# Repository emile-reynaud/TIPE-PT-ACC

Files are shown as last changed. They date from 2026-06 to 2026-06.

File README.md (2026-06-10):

# Régulateur de vitesse adaptatif et boucle de rétroaction PID
## TIPE PTSI-PT
### 2024-2026

---

## Sommaire

0. [Description générale](#desc)
   - [Problématique](#prob)
   - [Ancrage au thème *Cycles et boucles*](#anc-th)
1. [Maquette](#model)
2. [Architecture du correcteur](#arch-corr)
   - [Description de feedforward](#desc-ff)
   - [Identification du moteur](#id-mot)
3. [Mesure de vitesses](#mes-vit)
4. [Protocole expérimental](#prot-exp)
5. [Résultats](#results)
   - [Correcteur P](#P-results)
   - [Correcteur PI](#PI-results)
   - [Correcteur PD](#PD-results)
   - [Correcteur PID](#PID-results)
6. [Conclusion](#concl)
7. [Annexes et bibliographies](#annex)

---

## <a name="desc">Description générale</a>

Ce repo est un projet de recherche motivé par l'épreuve de TIPE du concours Banque PT.

Le projet est de construire une maquette d'un **régulateur de vitesse adaptatif** ou **ACC** (**A**daptive **C**ruise **C**ontrol), et de faire des expériences sur sa boucle de correction pour comparer les différents correcteurs **P**roportionnel (**P**), **P**roportionnel-**I**ntégral (**PI**), **P**roportionnel-**D**érivé (**PD**) et **P**roportionnel-**I**ntégral-**D**érivé (**PID**).

### <a name="prob">Problématique</a>

Comment un régulateur de vitesse adaptatif fonctionne-t-il, et comment sa boucle de correction PID se comporte-t-elle ?

### <a name="anc-th">Ancrage au thème *Cycles et boucles*</a>

Ce TIPE se concentre sur la **boucle** de rétroaction, ou **boucle** de correction, du système. Le **cycle** de correction est éffectué toutes les 50 ms.

## <a name="model">Maquette</a>

La maquette est composée d'une voiture RC modifiée et équipée de :

- Moteur brushed RC390
- Pont en H L298N
- Arduino Nano Every
- Arduino Nano Connector Carrier
- Capteur de distance à ultrasons HC-SR04
- Capteur à effet Hall + 3 aimants dans la roue arrière gauche
- Carte microSD branchée dans le Connector Carrier

##### Voici quelques images de la maquette

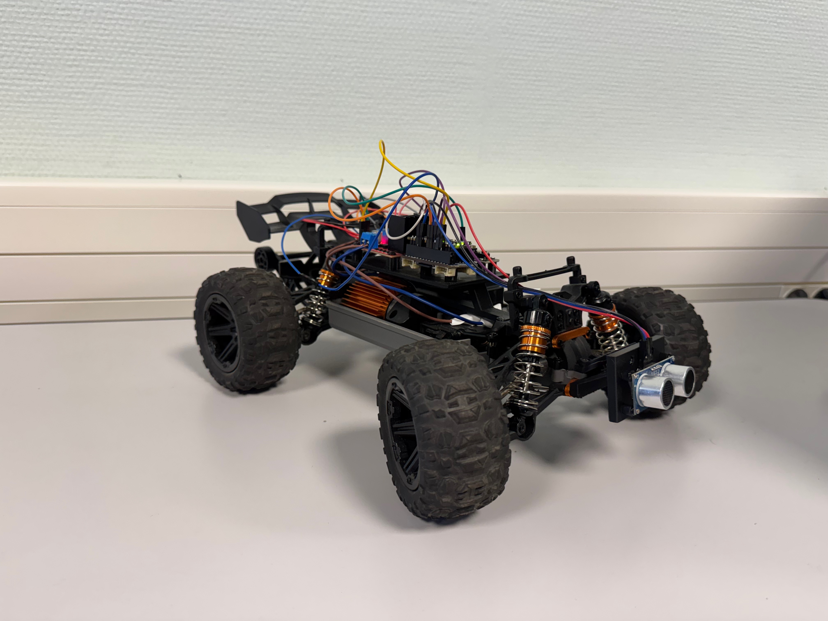
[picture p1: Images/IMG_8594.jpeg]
Model Overview 3/4 front right


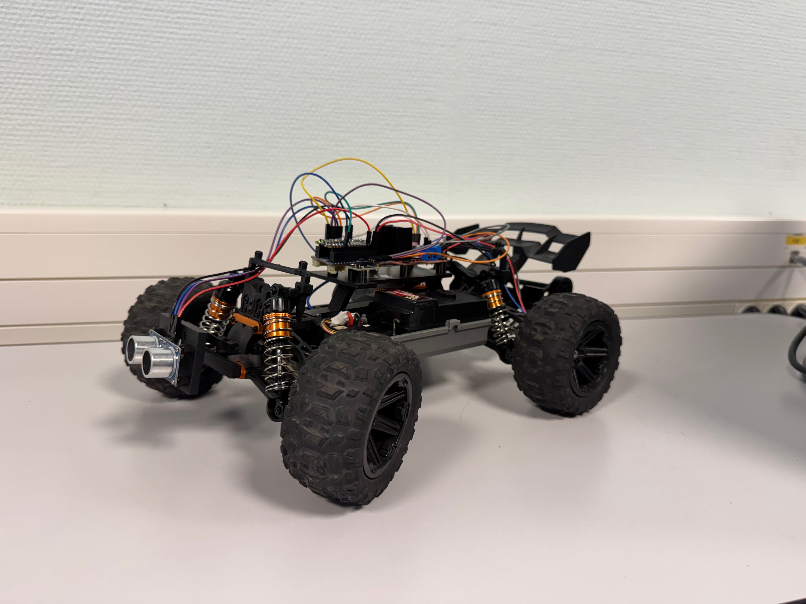
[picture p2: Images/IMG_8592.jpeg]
Model Overview 3/4 front left


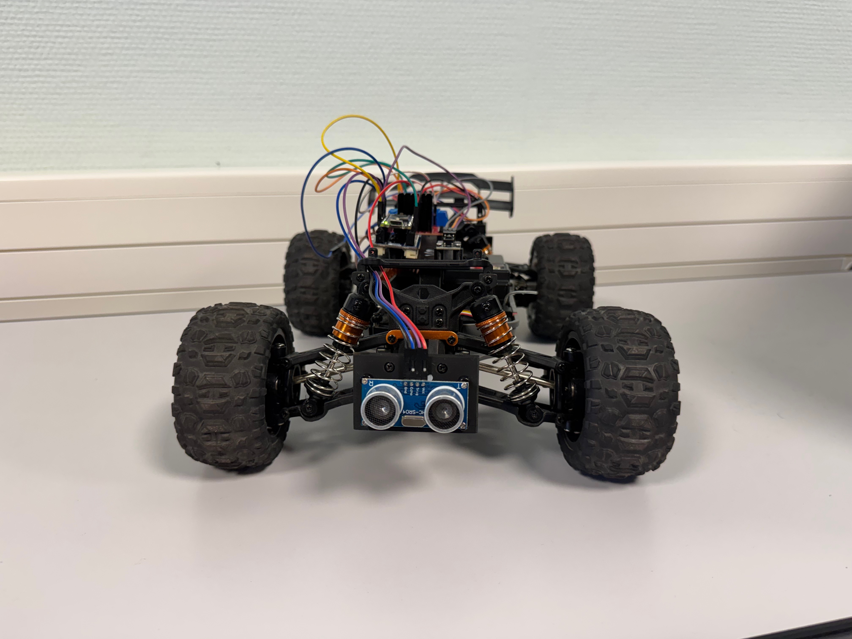
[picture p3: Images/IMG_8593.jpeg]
Model Overview face front


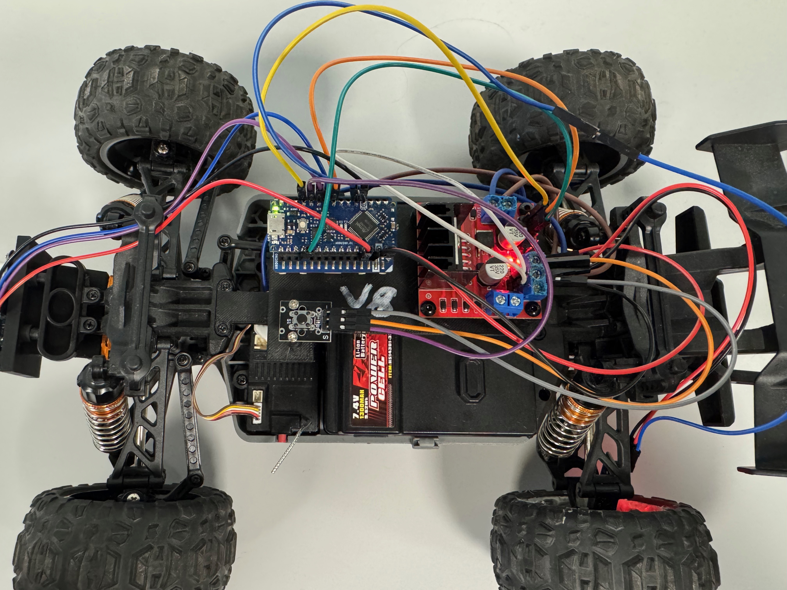
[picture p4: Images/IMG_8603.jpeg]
Electronics Overview


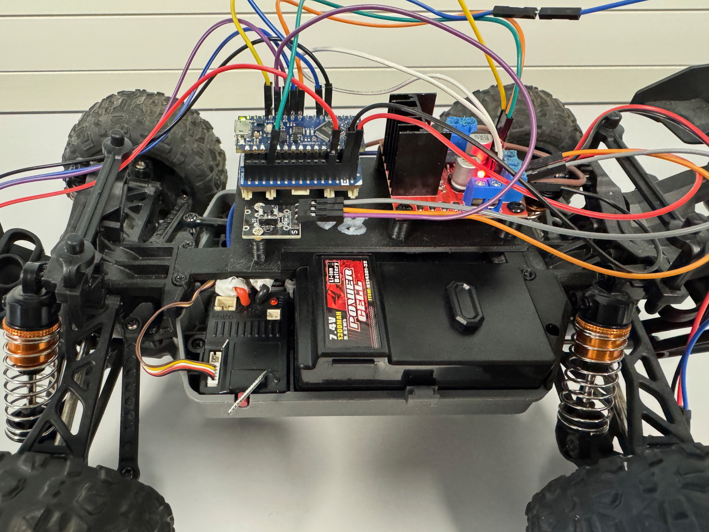
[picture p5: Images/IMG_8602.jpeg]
Electronics Overview left-side view


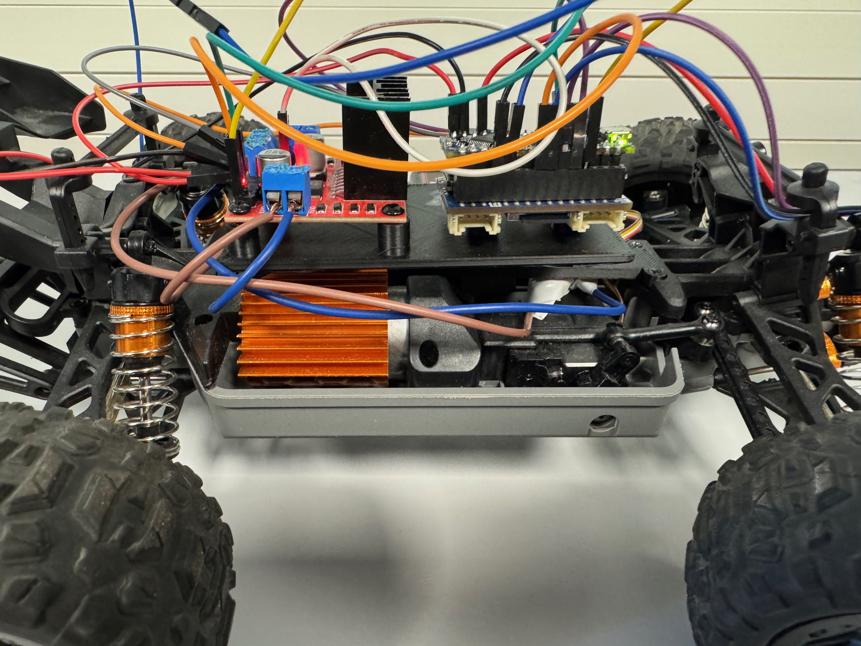
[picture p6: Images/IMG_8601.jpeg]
Electronics Overview right-side view


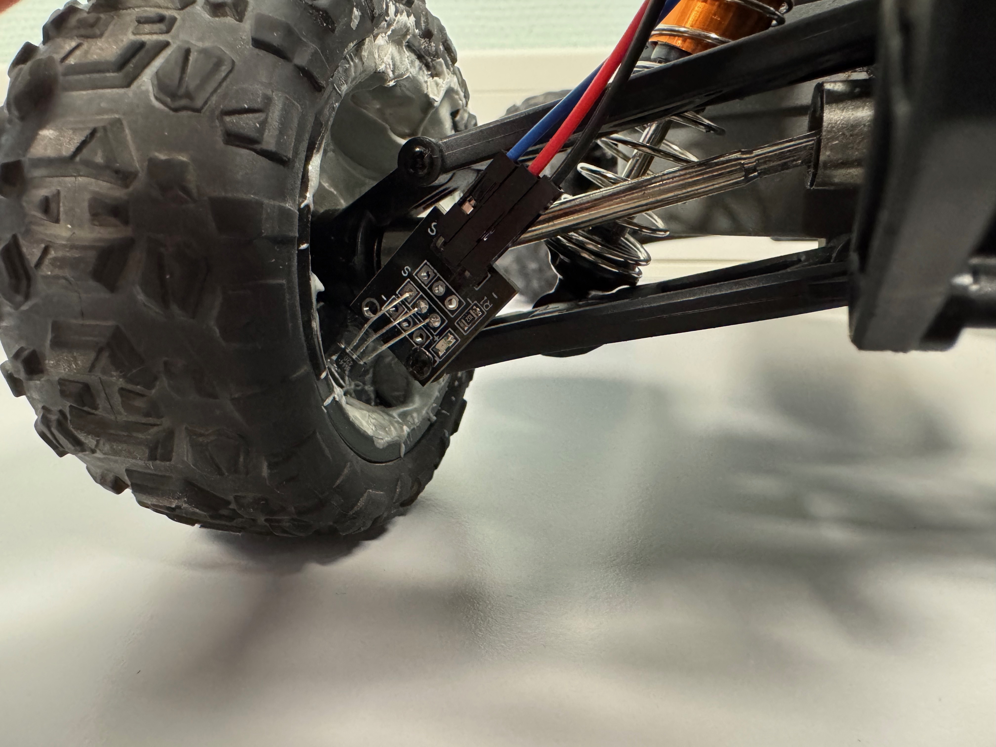
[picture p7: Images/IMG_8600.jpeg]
Hall effect sensor


## <a name="arch-corr">Architecture du correcteur</a>

Le correcteur se compose du régulateur PID, mais aussi d'un sytème de *feedforward*.

### <a name="desc-ff">Description du feedforward</a>

Le correcteur, qu'il soit P, PI, PD ou PID, prend une erreur en entrée et renvoie une commande moteur, et il veut faire tendre l'entrée vers 0.
Or, s'il fait cela, la commande qu'il retournera sera elle aussi 0.
Cependant, à 0, le moteur ne maintient pas sa vitesse à cause de la zone morte créée par le moteur en dessous de 76 PWM.

Voilà pour nous avons besoin dans ce sytème d'un **feedforward**.
Le feedforward est simplement un ajout après les correcteur, permettant de corriger cela et faire tendre la commande vers une commande en régime, et non en roue libre.
C'est une sorte d'offset de la commande.

### <a name="id-mot">Identification du moteur</a>

Pour calculer la valeur du feedforward, nous avons besoin d'identifier le moteur et de trouverson gain statique K, sa constante de temps $\tau$, ainsi que son seuil de commande.

Voici la fonction transfert d'un moteur à courant continu :

$\frac{dv}{dt} + \frac{1}{\tau}\cdot{v(t)} = K\cdot{u(t)}$

On trouve en la résolvant :

$v(t) = K\cdot{U_{0}}\cdot{(1-\exp(\frac{-t}{\tau}))}$
en réponse à un échelon U<sub>0</sub>

#### Protocole

- 9 échelons de 40 à 240 PWM, 3 s chacun.
- Mesure de v<sub>∞</sub> et $\tau$

#### Formules

On sait que :

$K = \frac{v_{\infty}}{U_{0}} \text{ et } v(\tau) = 0,632 \times v_{\infty}$

#### Résultats

- K = 1,4 m⋅s<sup>-1</sup>
- $\tau$ = 250 ms
- Seuil = 0,30 (= 76/255)

$\text{Donc } U_{FF} = (\frac{V_{c}}{K} + \{ Seuil }) = (\frac{0,7}{1,4} + 0,3) \times 255 = 204 \text{ PWM}$

Au final, la commande aura donc cette forme : 

$u(t) = U_{FF} + Kp \cdot \varepsilon + Ki \cdot \int \varepsilon \cdot dt + Kd \cdot \frac{d\varepsilon}{dt}$

## <a name="mes-vit">Mesure de vitesses</a>

La méthode de mesure de vitesse utilisée dans le programme est la **méthode période**. La méthode la plus commune est la méthode fréquencemétrique.

### Méthode fréquencemétrique

Le principe est de prendre un intervalle de temps et de compter le nombre de passage d'un objet, d'aimants dans mon cas, devant un capteur.
Je n'ai que 3 aimants donc les incertitudes dépendent de la vitesse et sont donc très grandes à basse vitesse notamment.

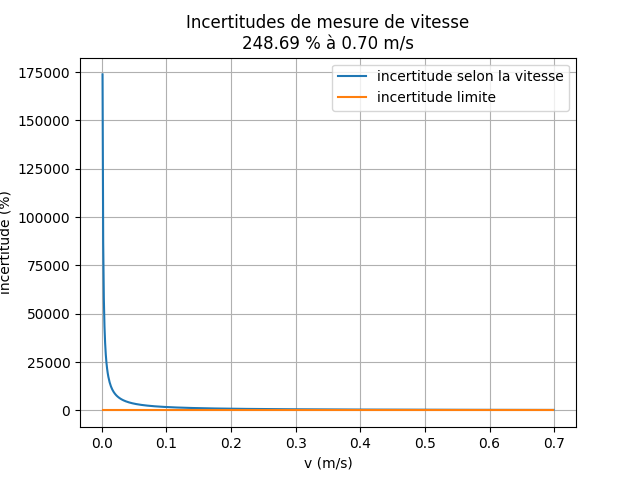
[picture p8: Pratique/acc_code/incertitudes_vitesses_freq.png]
Courbes incertitudes méthode fréquencemétrique


### Méthode période

C'est l'inverse de la méthode fréquencemétrique. On mesure le temps entre le passage de deux aimants.
L'incertitude est donc moins grande et surtout elle est constante.

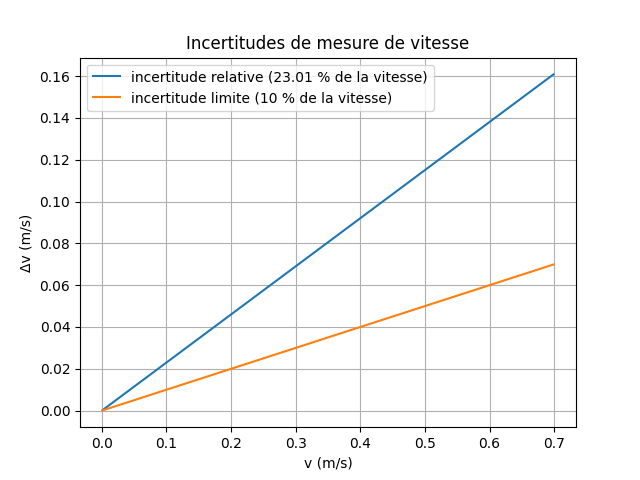
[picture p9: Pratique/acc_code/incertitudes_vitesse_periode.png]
Courbes incertitudes méthode période


## <a name="prot-exp">Protocole expérimental</a>

- Démarrage : 0-3s
  - Kick-start moteur pour franchir la zone morte et les frottements
- Mode vitesse : 3-12s
  - Aucun obstacle
- Mode distance : 12-27s
  - 12-15s : obstacle 0,6 m → 0,15 m
  - 15-21s : obstacle maintenu à 0,15 m
  - 21-27s : obstacle 0,15 m → 1,20 m
- Mode vitesse : 27-35s

## <a name="results">Résultats</a>

### <a name="P-results">Correcteur P</a>

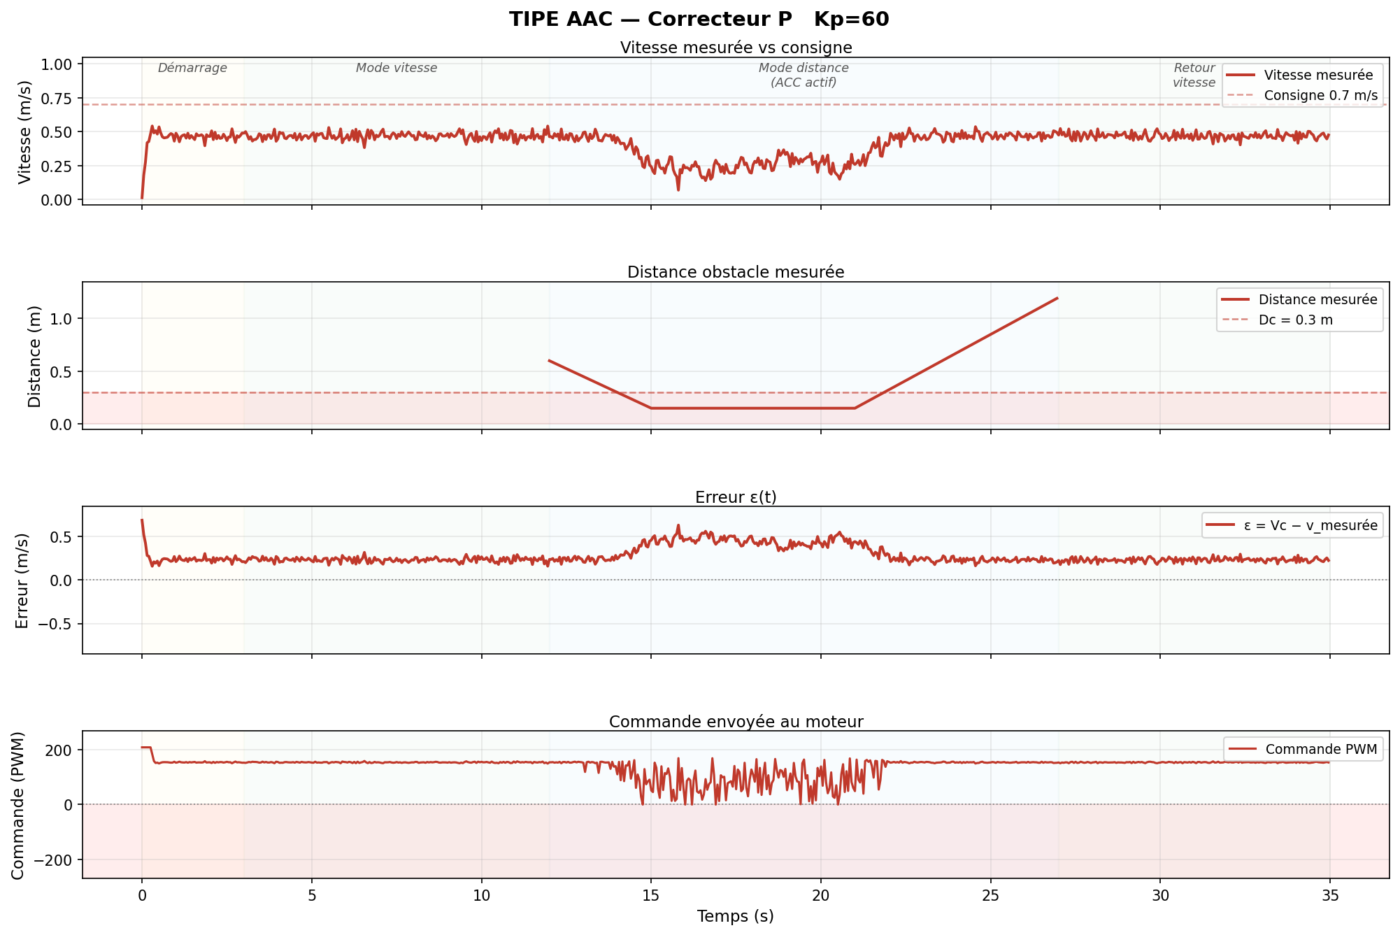
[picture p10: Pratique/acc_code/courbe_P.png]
Courbes expérimentales P


#### Analyse

##### Positif

- Kick-start efficace
- Commande stable à 170-180 PWM en régime sans obstacle

##### Limites

- Erreur statique -0,23 m⋅s<sup>-1</sup> (33%) structurelle sans intégrale
- Commande saccadée en mode distance (bruit amplifié par Kp)
- t<sub>r<sub>5%</sub></sub> = N/A, la vitesse ne converge jamais vers V<sub>c</sub>

#### Bilan

L'erreur statique de 33 % est irréductible sans terme intégral. Sert de référence comparative.

### <a name="PI-results">Correcteur PI</a>

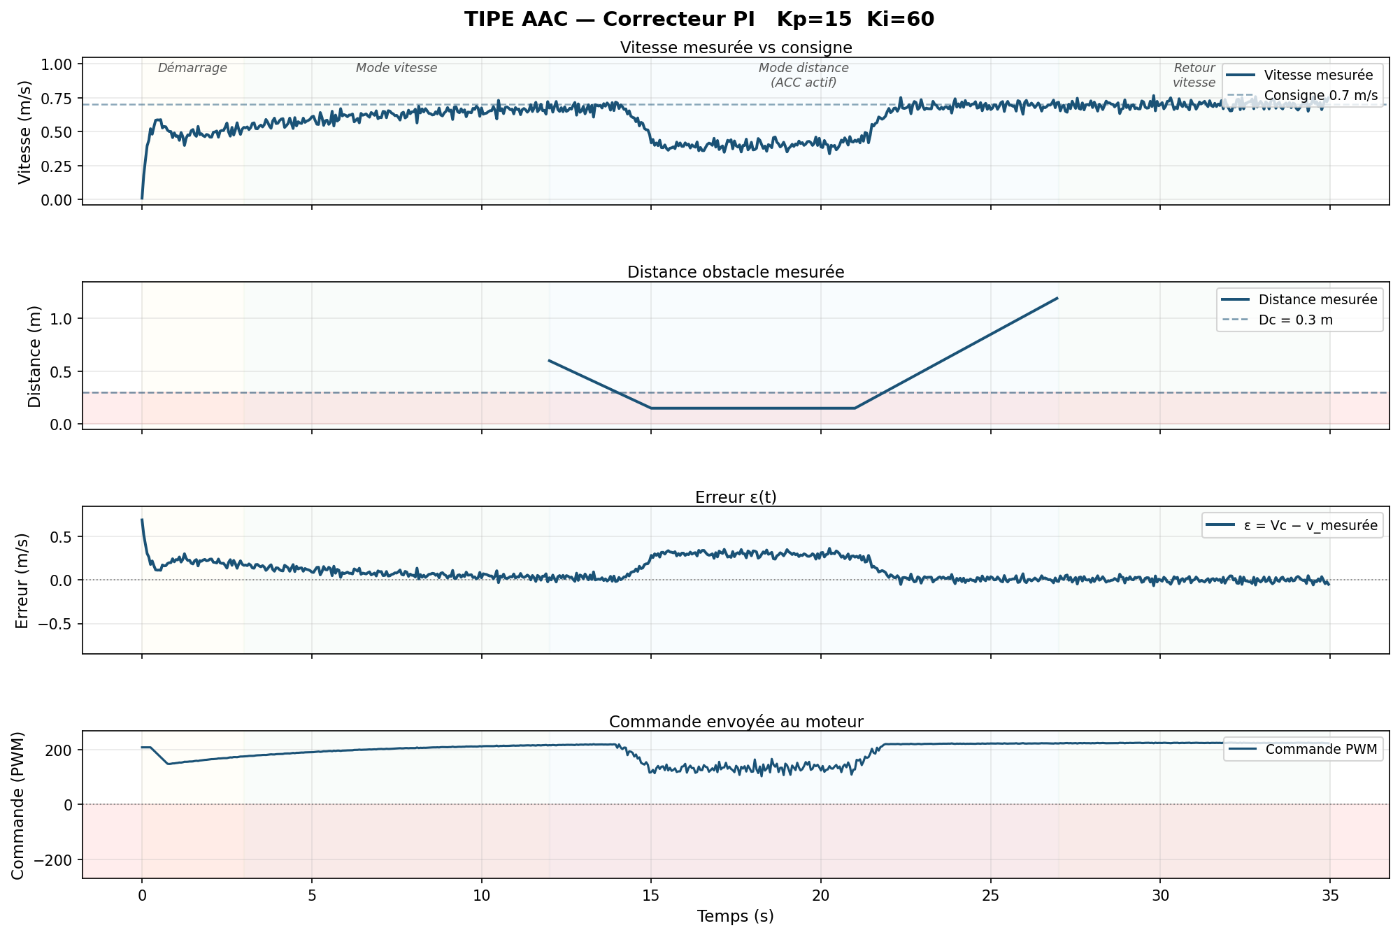
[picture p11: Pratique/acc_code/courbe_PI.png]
Courbes expérimentales PI


#### Analyse

##### Positif

- Erreur statique → 0 : Ki compense l'erreur
- Aucun dépassement, système très amorti
- Transition entre les modes propres, pas de saut

##### Limites

- t<sub>r<sub>5%</sub></sub> = 7,5 s, le plus lent des correcteurs
- Kp = 15 volontairement faible, peu réactif au perturbations soudaines
- Réinitialisation de l'intégrale au kick, convergence repart à zéro après démarrage

#### Bilan

Le PI atteint la précision au prix de la rapidité. t<sub>r<sub>5%</sub></sub> = 7,5 s est rédhibitoire en conditions réelles. À 0,70 m⋅s<sup>-1</sup>, la voiture parcourt 5 mètres avant d'être à vitesse.

### <a name="PD-results">Correcteur PD</a>

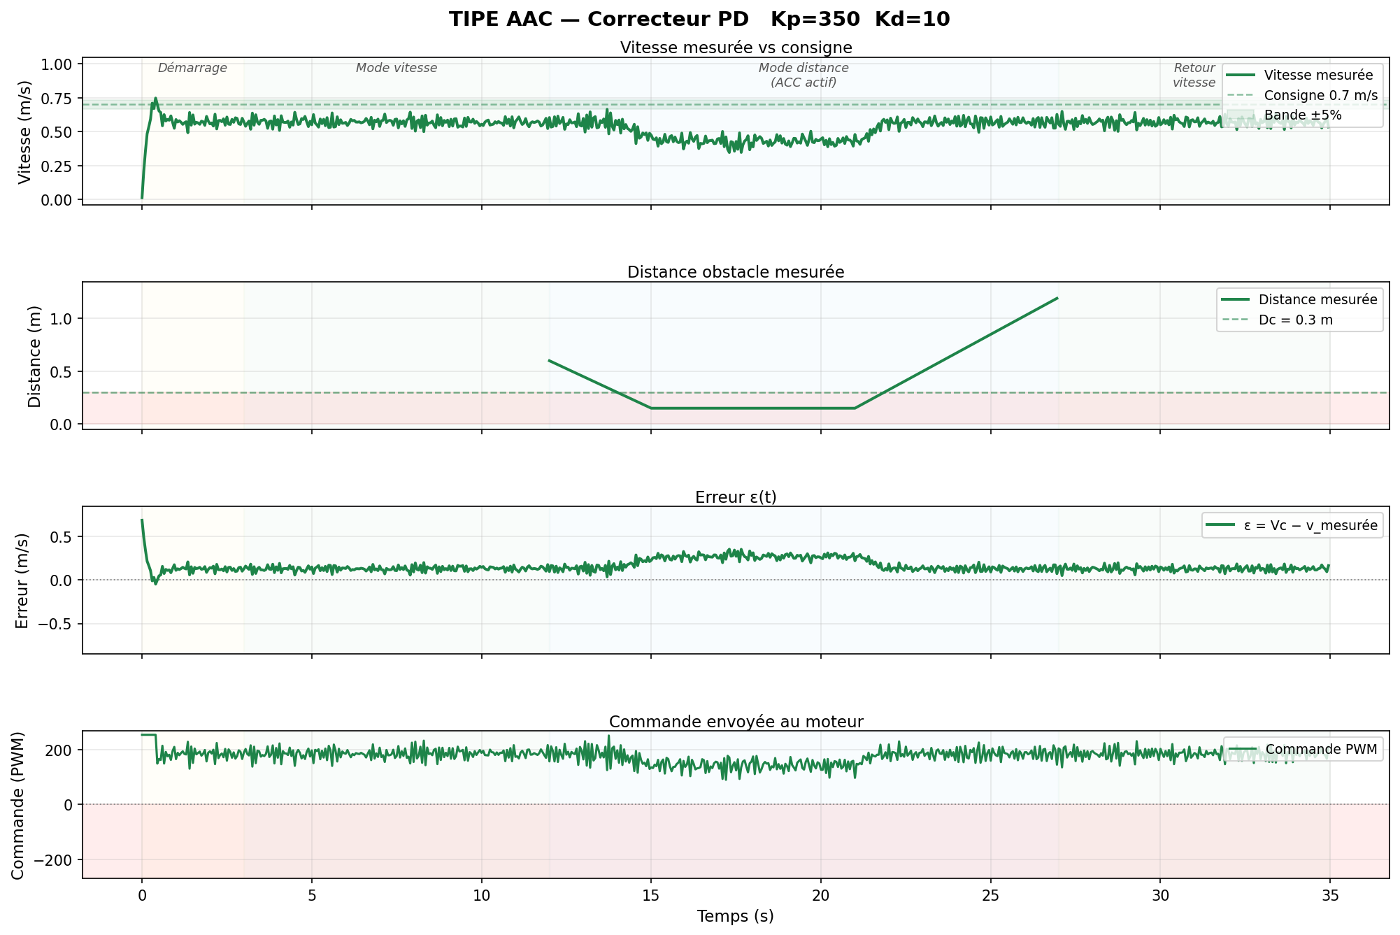
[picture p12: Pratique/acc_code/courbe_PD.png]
Courbes expérimentales PD


#### Analyse

##### Positif

- t<sub>r<sub>5%</sub></sub> = 1,5 s, le plus rapide

##### Limites

- Erreur statique −0,13 m⋅s<sup>-1</sup> (19 %), irréductible sans terme intégral
- Dépassement 14 % > norme standard 5 % — non conforme

#### Bilan

Le PD est rapide mais imprécis. Dépassement 14 % dépasse la norme de 5 %. Sans intégrale, l'erreur statique de 19 % persiste indéfiniment. Bon transitoire, mauvais état final.

### <a name="PID-results">Correcteur PID</a>

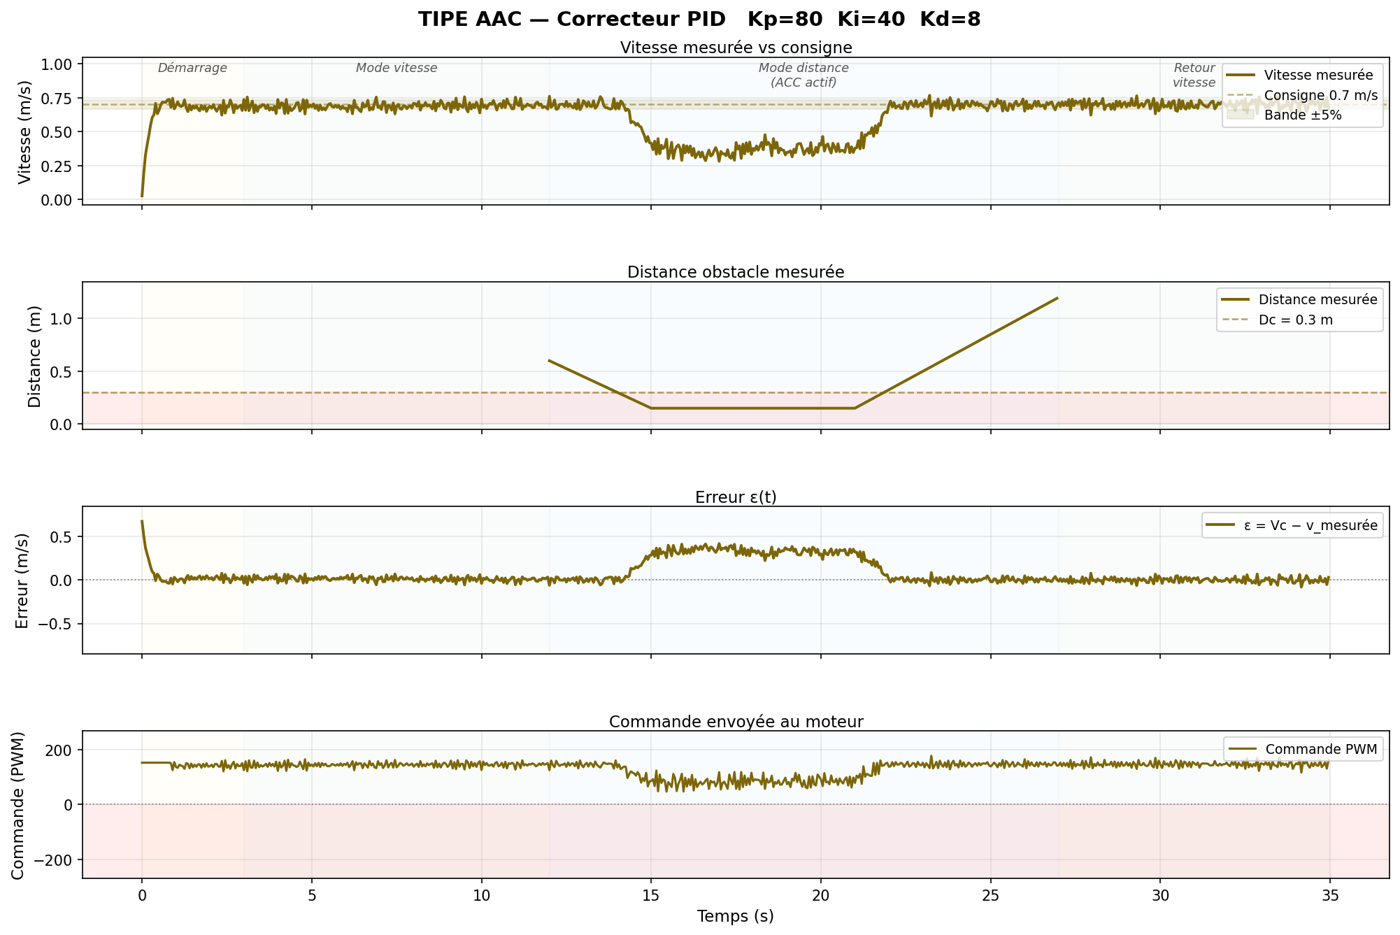
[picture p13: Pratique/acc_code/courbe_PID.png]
Courbes expérimentales PID


#### Analyse

##### Positif

- Erreur statique < 1 % (−0,01 m⋅s<sup>-1</sup>)
- Dépassement 4,8 % < 5 %
- t<sub>r<sub>5%</sub></sub> = 4 s, bon compromis rapidité / stabilité
- Mode distance ACC propre

##### Limites

- Réglage plus complexe : 3 paramètres interdépendants (Kp, Ki, Kd)
- Anti-windup nécessaire : intégrale gelée pendant le freinage en mode distance
- Terme D sensible au bruit Hall

#### Bilan

Seul le PID satisfait simultanément les 3 critères : erreur < 1 %, dépassement 4,8 % ≤ 5 %, t<sub>r<sub>5%</sub></sub> = 4 s. L'architecture FF + PID constitue la solution optimale.

## <a name="concl">Conclusion</a>

#### Limites

- 3 aimants : oscillations persistantes
- K varie avec batterie → re-identification nécessaire
- HC-SR04 : fausses détections en extérieur
- Zone morte 76/255 → oscillations irréductibles

#### Perspectives

- 12 aimants → Δv_freq divisé par 4
- Encodeur optique → résolution µm
- 2e maquette → obstacle mobile réaliste
- Re-identification auto (K adaptatif)

## <a name="annex">Annexes et bibliographies</a>

#### Bibliographie

1. V.K. Kukkala, J. Tunnell, S. Pasricha, T. Bradley — "Advanced Driver-Assistance Systems: A Path Toward Autonomous Vehicles" — IEEE Consumer Electronics Magazine, vol. 7, n°5, pp. 18-25, 2018. DOI: 10.1109/MCE.2018.2828440
2. J.E. Naranjo, F. Serradilla, F. Nashashibi — "Speed Control Optimization for Autonomous Vehicles with Metaheuristics" — Electronics 2020, 9, 551. DOI: 10.3390/electronics9040551
3. Saravanan G et al. — "Red Panda Optimization Algorithm-Based PID Controller Design for Automobile Cruise Control System" — ICSSEECC 2024. DOI: 10.1109/ICSSEECC61126.2024.10649422
4. J.S. Saputro et al. — "Design of an Adaptive Cruise Control System using PID Control Method on Electric Vehicle Prototypes" — ICAMIMIA 2023. DOI: 10.1109/ICAMIMIA60881.2023.10427856

#### Annexes

Pour voir le code, allez voir ce [fichier](/Pratique/acc_code/AAC_TIPE_v19/AAC_TIPE_v19.ino).

Pour une présentation un peu plus détaillée et mise en forme, allez voir la [présentation](/TIPE_AAC_v5.pdf).

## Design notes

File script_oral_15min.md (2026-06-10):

# Script oral — TIPE AAC — 15 minutes chrono
> **Règle d'or : une diapo = 1 minute maximum. Parlez lentement, voix posée.**  
> Chaque section indique la durée cible et les points à ne pas oublier.

---

## DIAPO 1 — Titre *(30 secondes)*

« Bonjour. Mon TIPE porte sur la conception et la comparaison expérimentale de correcteurs PID appliqués à un régulateur de vitesse adaptatif — un ACC miniature construit sur une voiture RC.
L'ancrage au thème "Cycles et boucles" est immédiat : le cœur du système est une boucle de régulation fermée, exécutée en cycle discret toutes les 50 millisecondes. »

---

## DIAPO 2 — Problématique *(50 secondes)*

« La structure classique d'un régulateur en boucle fermée : on compare la consigne à la mesure, l'écart ε alimente le correcteur, qui agit sur le moteur, et le capteur ferme la boucle.

La problématique est : quel correcteur — P, PI, PD ou PID — associé à une commande par anticipation offre le meilleur compromis entre stabilité, précision et temps de réponse pour un ACC miniature ?

L'ancrage au thème est direct : cette boucle est un cycle discret — mesure, calcul, action — répété 20 fois par seconde. »

---

## DIAPO 3 — Maquette *(55 secondes)*

« La maquette embarque cinq composants clés.
Un Arduino Nano Every joue le rôle de calculateur. Un pont en H L298N pilote le moteur RC390 par PWM.
Un HC-SR04 mesure la distance à l'obstacle jusqu'à 1,2 mètre. Trois aimants et un capteur Hall mesurent la vitesse de la roue.
Tout est enregistré sur microSD en CSV à 10 Hz pour analyse post-expérience.

Les consignes : vitesse de croisière 0,70 m/s, distance de sécurité 0,30 m, boucle de contrôle à 50 ms. »

---

## DIAPO 4 — Identification du moteur *(60 secondes)*

« Avant de concevoir le correcteur, il faut modéliser le moteur.
On identifie un modèle de premier ordre : la vitesse d'équilibre est proportionnelle à la commande au-delà d'un seuil de démarrage.
K = 1,40 m/s est le gain statique. Le seuil θ = 0,30 normalisé, soit 76 PWM, est la commande minimale pour vaincre le frottement.

De là, on calcule le feedforward : U_FF = (Vc/K + θ) × 255 = 204 PWM. C'est la commande d'équilibre qui place le moteur directement au bon point de fonctionnement — sans ça, le correcteur P seul aurait toujours une erreur statique.

Cette architecture 2-DOF — feedforward plus PID — est le standard industriel. »

---

## DIAPO 5 — Mesure de vitesse *(55 secondes)*

« On dispose de deux méthodes complémentaires.
La méthode fréquencemétrique compte les impulsions Hall sur 50 ms — elle est précise à haute vitesse mais aveugle à basse vitesse. On l'utilise pour le log uniquement.

La méthode période mesure la durée entre deux aimants consécutifs — 155 fois plus précise à basse vitesse. C'est elle qui alimente le correcteur PID.

Un filtre IIR asymétrique la protège : montée lente (alpha 0,25) pour ignorer les rebonds mécaniques, descente rapide (alpha 0,85) pour suivre les vraies décélérations sans retard.

L'incertitude de 2,3 % se traduit par le bruit visible sur les courbes. »

---

## DIAPO 6 — Architecture + mode ACC *(60 secondes)*

« En mode vitesse, l'architecture est 2-DOF : feedforward plus PID sur l'erreur de vitesse.

En mode distance — quand un obstacle est détecté — voici l'innovation v19 :  
**cmd = cmd_vitesse − K_brake × max(0, Dc − d)**

Si l'obstacle est loin (d ≥ Dc) : le freinage est nul, la voiture maintient exactement sa vitesse de croisière — elle n'accélère pas vers l'obstacle.
Si l'obstacle est trop proche (d < Dc) : le freinage est proportionnel à l'excès de proximité.

Un anti-windup gèle l'intégrale pendant le freinage pour éviter une accélération parasite au retour. »

---

## DIAPO 7 — Correcteur P *(55 secondes)*

« Sur la courbe P, on voit clairement l'erreur statique : la voiture se stabilise à 0,47 m/s au lieu de 0,70 — soit 33% d'écart.

Cette erreur est structurelle : le terme P seul calcule u = Kp × ε. À l'équilibre, ε tend vers une valeur non nulle car le feedforward ne compense pas parfaitement le mismatch entre K nominal et K réel — liée à la décharge de la batterie.

En mode distance, regardez la commande — sans lissage, le bruit de mesure amplifié par Kp=60 crée les saccades caractéristiques visibles dans le quatrième graphe.

Le P seul est clairement insuffisant pour un ACC. »

---

## DIAPO 8 — Correcteur PI *(55 secondes)*

« Le PI introduit l'intégrale, qui s'accumule tant que l'erreur persiste.
Avec Ki = 60, la compensation du mismatch de K prend environ 8 secondes — visible sur la courbe par la montée progressive vers 0,70 m/s.

Le prix à payer : un temps de réponse de 7,5 secondes. Le Kp = 15 est volontairement faible pour maintenir la stabilité malgré le fort Ki — système très amorti, aucun dépassement.

Ce système est précis mais trop lent pour un ACC réel : en 7,5 secondes à 0,70 m/s, la voiture parcourt plus de 5 mètres. »

---

## DIAPO 9 — Correcteur PD *(55 secondes)*

« Le PD — ici avec Kp = 350 et Kd = 10 — est l'opposé du PI : très rapide, imprécis.

Le temps de réponse est inférieur à 2 secondes. Le terme dérivé amortit partiellement la montée, mais on voit un dépassement de 14% — au-dessus de la norme standard de 5%.

L'erreur statique de 0,13 m/s est réduite par rapport au P simple grâce au Kp plus élevé, mais irréductible sans intégrale.

À noter : j'ai implémenté la dérivée sur la mesure de vitesse et non sur l'erreur pour éviter le "derivative kick" — le pic brutal qui apparaît quand la consigne change soudainement. »

---

## DIAPO 10 — Correcteur PID *(60 secondes)*

« Le PID combine les trois termes et donne les meilleurs résultats sur tous les critères.

L'intégrale (Ki = 40) élimine l'erreur statique — la voiture atteint 0,70 m/s.
Le dérivé (Kd = 8) amortit le dépassement à 4,8%, en dessous de la norme standard de 5%.
Le temps de réponse est de 4 secondes — bon compromis.

En mode distance, regardez la vitesse : elle reste constante jusqu'à ce que l'obstacle soit trop proche, puis décroît progressivement. Pas d'accélération vers l'obstacle. À droite du graphe, au retour en mode vitesse, la remontée vers Vc est propre.

C'est le seul correcteur à satisfaire simultanément les trois critères. »

---

## DIAPO 11 — Comparaison synthèse *(50 secondes)*

« Ce tableau résume toutes les performances mesurées.

P : inacceptable — erreur statique de 33%, jamais éliminée.
PI : précis mais trop lent — 7,5 secondes pour atteindre la consigne.
PD : rapide mais imprécis — dépassement de 14%, au-dessus de la norme.
PID : les trois critères sont respectés simultanément.

La réponse à la problématique est donc claire : le PID associé au feedforward 2-DOF est le meilleur compromis. Les correcteurs partiels — P, PI, PD — présentent chacun un défaut rédhibitoire en conditions réelles. »

---

## DIAPO 12 — Innovations v19 *(55 secondes)*

« Pour obtenir ces courbes propres, quatre choix d'implémentation ont été nécessaires.

Premièrement, la dérivée sur la mesure de vitesse — mathématiquement équivalente en régime stable, mais sans le pic brutal au changement de consigne.

Deuxièmement, la continuité de l'intégrale entre les modes vitesse et distance — c'est ce qui supprime l'accélération parasite au passage en mode ACC.

Troisièmement, l'anti-windup spécifique au freinage — sans ça, l'intégrale s'emballe pendant le ralentissement et fait accélérer la voiture après.

Quatrièmement, le kick-start adapté à chaque correcteur pour reproduire les comportements transitoires caractéristiques. »

---

## DIAPO 13 — Limites *(45 secondes)*

« Quatre limites identifiées.
Le HC-SR04 avec 2 cm de résolution crée des oscillations de commande — un LiDAR ToF améliorerait la précision d'un facteur 10.
Le capteur Hall à 3 aimants génère un bruit périodique à 8 Hz — 6 aimants réduiraient l'incertitude de moitié.
La décharge de la batterie fait baisser K de 40% — un observateur adaptatif corrigerait cette dérive.
En ACC réel, la distance de sécurité devrait croître avec la vitesse selon le concept de headway time. »

---

## DIAPO 14 — Conclusion *(40 secondes)*

« En conclusion : l'architecture 2-DOF avec correcteur PID est la solution optimale pour ce système.
Les critères sont validés expérimentalement : erreur statique inférieure à 1%, dépassement de 4,8% conforme à la norme de 5%, temps de réponse de 4 secondes.
Le mode ACC v19 reproduit le comportement d'un vrai régulateur de vitesse adaptatif.
Et l'ancrage au thème est fort : la boucle fermée de régulation est littéralement un cycle discret — mesure, calcul, action — incarnant la notion de "Cycles et boucles". »

---

## DIAPO 15 — Bibliographie *(20 secondes)*

« Les quatre références utilisées couvrent le contexte industriel des ADAS et les aspects techniques du contrôle PID sur Arduino. Je reste disponible pour toute question. »

---

## Chronomètre estimé

| Diapo | Contenu | Durée |
|---|---|---|
| 1 | Titre | 0:30 |
| 2 | Problématique | 1:20 |
| 3 | Maquette | 2:15 |
| 4 | Identification | 3:15 |
| 5 | Mesure vitesse | 4:10 |
| 6 | Architecture + ACC | 5:10 |
| 7 | Correcteur P | 6:05 |
| 8 | Correcteur PI | 7:00 |
| 9 | Correcteur PD | 7:55 |
| 10 | Correcteur PID | 8:55 |
| 11 | Comparaison | 9:45 |
| 12 | Innovations v19 | 10:40 |
| 13 | Limites | 11:25 |
| 14 | Conclusion | 12:05 |
| 15 | Bibliographie | 12:25 |
| **Marge questions** | | **2:35** |
| **TOTAL** | | **≤ 15:00** |

> 💡 **Conseil** : les diapos de courbe (7–10) peuvent se résumer en 45 s si tu as du retard. La comparaison (11) et la conclusion (14) sont les deux points à tenir coûte que coûte.

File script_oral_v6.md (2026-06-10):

# Script oral — TIPE AAC v4 + protocole — 15 minutes
> **20 slides. La diapo protocole est la n°8, entre "Architecture" et "Courbe P".**

---

## Diapo 1 — Titre *(30 s)*

« Bonjour. Mon TIPE porte sur la conception et la comparaison expérimentale de correcteurs PID pour un régulateur de vitesse adaptatif — un ACC miniature sur voiture RC. L'ancrage au thème "Cycles et boucles" est la boucle de régulation elle-même, exécutée en cycle discret toutes les 50 ms. »

---

## Diapo 2 — Ancrage et problématique *(45 s)*

« La boucle de régulation est un cycle classique : consigne, correcteur, actionneur, mesure — répété 20 fois par seconde. C'est le cœur de l'ancrage au thème. La problématique : quel correcteur P, PI, PD ou PID associé à un feedforward offre le meilleur compromis stabilité-précision pour un ACC miniature ? »

---

## Diapo 3 — Maquette *(40 s)*

« La maquette : Arduino Nano Every pour le calcul, pont en H L298N pour le moteur, HC-SR04 pour la distance obstacle, capteur Hall à 3 aimants pour la vitesse, microSD pour le log CSV à 10 Hz. »

---

## Diapo 4 — Identification du moteur *(55 s)*

« Le moteur est modélisé par un premier ordre : v = K × (u − seuil). Neuf échelons PWM donnent K = 1,4 m/s, τ = 250 ms, seuil = 0,30. De là, le feedforward U_FF = 204 PWM. Sans ce feedforward, le PID seul s'annulerait quand l'erreur tend vers zéro — le moteur s'arrêterait. C'est l'architecture 2-DOF : FF pour le point de fonctionnement, PID pour les perturbations. »

---

## Diapo 5 — Mesure fréquencemétrique *(35 s)*

« La méthode fréquencemétrique compte les impulsions Hall sur 50 ms — incertitude de 249 % à 0,70 m/s, inutilisable pour le PID. Je l'utilise uniquement pour le log. »

---

## Diapo 6 — Mesure période *(40 s)*

« La méthode période mesure la durée entre deux aimants consécutifs — 155 fois plus précise, incertitude 2,3 %. C'est elle qui alimente le correcteur. Un filtre IIR asymétrique la protège contre les rebonds tout en suivant rapidement les décélérations. »

---

## Diapo 7 — Architecture 2-DOF + mode ACC *(55 s)*

« L'architecture 2-DOF : U_FF positionne le moteur au point d'équilibre, le PID corrige les écarts. En mode distance, j'applique une loi ACC réaliste : cmd = cmd_vitesse − 600 × max(0, Dc − d). Si l'obstacle est loin, freinage nul — la voiture maintient sa vitesse sans accélérer vers l'obstacle. Si l'obstacle est trop proche, freinage proportionnel à l'excès de proximité. »

---

## Diapo 8 — Protocole expérimental *(50 s)*

« Avant de présenter les courbes, voici le protocole commun aux 4 correcteurs. La frise montre 35 secondes divisées en 4 phases. Phase 1 : kick-start de 0 à 3 s — la durée et la puissance varient selon le correcteur. Phase 2 : mode vitesse de 3 à 12 s, sans obstacle — on y mesure l'erreur statique, le dépassement et le tr5%. Phase 3 : mode distance ACC de 12 à 27 s — l'obstacle approche sous la distance de sécurité puis s'éloigne. Phase 4 : retour en mode vitesse de 27 à 35 s. Les paramètres communs sont rappelés en bas. »

---

## Diapo 9 — Correcteur P — courbe *(40 s)*

« Sur la courbe P, Kp = 60. L'erreur statique est immédiatement visible : la voiture se stabilise à 0,47 m/s au lieu de 0,70 — 33 % d'écart. En mode distance, regardez la commande : les saccades caractéristiques dues au bruit amplifié par Kp sans lissage. »

---

## Diapo 10 — Correcteur P — analyse *(35 s)*

« Erreur statique de 33 % structurelle — irréductible sans terme intégral. K_réel ≠ K_nom à cause de la batterie, le feedforward ne compense pas entièrement. Le P sert de référence comparative. »

---

## Diapo 11 — Correcteur PI — courbe *(40 s)*

« PI, Kp = 15 et Ki = 60. La montée progressive vers 0,70 m/s est visible — l'intégrale qui compense le biais en 8 secondes. Système très amorti, aucun dépassement. »

---

## Diapo 12 — Correcteur PI — analyse *(35 s)*

« L'intégrale élimine l'erreur statique, mais tr5% = 7,5 s — à 0,70 m/s la voiture parcourt 5 mètres avant d'atteindre la consigne. Trop lent pour un ACC réel. »

---

## Diapo 13 — Correcteur PD — courbe *(40 s)*

« PD, Kp = 350 et Kd = 10. Très rapide — tr5% ≈ 1,5 s — et le dépassement de 14 % est bien visible. La dérivée est calculée sur la mesure de vitesse, pas sur l'erreur, pour éviter le pic brutal lors des transitions. »

---

## Diapo 14 — Correcteur PD — analyse *(35 s)*

« Rapide mais imprécis : erreur statique de 19 % sans intégrale, et dépassement de 14 % au-delà de la norme de 5 %. Bon transitoire, mauvais état final. »

---

## Diapo 15 — Correcteur PID — courbe *(45 s)*

« PID, Kp = 80, Ki = 40, Kd = 8. Démarrage avec 4,8 % de dépassement, convergence vers 0,70 m/s en 4 secondes, erreur résiduelle sous 1 %. En mode distance, la vitesse reste stable jusqu'à ce que l'obstacle soit trop proche, puis le freinage s'active progressivement — sans aucune accélération vers l'obstacle. »

---

## Diapo 16 — Correcteur PID — analyse *(40 s)*

« Seul le PID satisfait les trois critères simultanément : erreur < 1 %, dépassement 4,8 % ≤ 5 %, tr5% = 4 s. L'anti-windup gèle l'intégrale pendant le freinage en mode distance pour éviter l'accélération parasite au retour. »

---

## Diapo 17 — Comparaison *(40 s)*

« Le tableau résume tout. P : erreur 33 %, éliminatoire. PI : précis mais 7,5 s. PD : rapide mais 14 % hors norme. PID : les trois critères respectés. La réponse à la problématique est claire. »

---

## Diapo 18 — Limites *(30 s)*

« Quatre limites : HC-SR04 résolution 2 cm, K qui varie avec la batterie, oscillations résiduelles liées à la zone morte, et inertie réelle légèrement supérieure au modèle. »

---

## Diapo 19 — Conclusion *(30 s)*

« PID + feedforward 2-DOF : solution optimale, critères validés expérimentalement. Mode distance ACC v19 : freinage seul, sans accélération vers l'obstacle. Ancrage : la boucle fermée est un cycle discret — mesure, calcul, action — répété 20 fois par seconde. »

---

## Diapo 20 — Bibliographie *(15 s)*

« Quatre références. Je reste disponible pour vos questions. »

---

## Chronomètre estimé

| # | Slide | Durée | Cumul |
|---|---|---|---|
| 1 | Titre | 0:30 | 0:30 |
| 2 | Ancrage + Problématique | 0:45 | 1:15 |
| 3 | Maquette | 0:40 | 1:55 |
| 4 | Identification moteur | 0:55 | 2:50 |
| 5 | Méthode fréquencemétrique | 0:35 | 3:25 |
| 6 | Méthode période | 0:40 | 4:05 |
| 7 | Architecture + mode ACC | 0:55 | 5:00 |
| **8** | **Protocole expérimental** | **0:50** | **5:50** |
| 9 | P — courbe | 0:40 | 6:30 |
| 10 | P — analyse | 0:35 | 7:05 |
| 11 | PI — courbe | 0:40 | 7:45 |
| 12 | PI — analyse | 0:35 | 8:20 |
| 13 | PD — courbe | 0:40 | 9:00 |
| 14 | PD — analyse | 0:35 | 9:35 |
| 15 | PID — courbe | 0:45 | 10:20 |
| 16 | PID — analyse | 0:40 | 11:00 |
| 17 | Comparaison | 0:40 | 11:40 |
| 18 | Limites | 0:30 | 12:10 |
| 19 | Conclusion | 0:30 | 12:40 |
| 20 | Bibliographie | 0:15 | 12:55 |
| **Marge** | | **2:05** | **≤ 15:00** |

> 💡 **Si tu es en avance** : développe les diapos d'analyse (10, 12, 14, 16) ou prends plus de temps sur la diapo protocole.
> **Si tu es en retard** : fusionne courbe + analyse oralement en une minute par correcteur, et condense les diapos 5+6 en 30 s : *« fréquencemétrique pour le log, période pour le PID — 155× plus précis »*.

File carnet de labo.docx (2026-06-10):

Carnet de labo

Emile Reynaud

Régulateur de vitesse adaptatif et boucle de rétroaction PID

Comment un régulateur de vitesse adaptatif fonctionne-t-il et comment sa boucle de correction se comporte-t-elle ?

Carnet de bord :

09/10/2024 : Première séance. Je me suis renseigné sur les boites de vitesses et leur fonctionnement. Je suis en recherche d’une problématique et d’expérimentation. J’ai également trouvé ma problématique. Je vais donc effectuer des recherches pour trouver une boite de vitesses à la casse et faire des mesures dessus pour voir s’il existe un lien entre la lubrification des pièces et le rendement de la boite.

13/11/2024 : Je me suis documenté sur le fonctionnement d’une boite de vitesses manuelle et d’un embrayage et j’ai également expliquer le fonctionnement de ceux-ci dans le carnet de labo. J’ai également commencé les recherches pour une boite de vitesses et comment la démonter et la mettre sur banc. M. Fourcade m’a dit que c’était un bon sujet.

11/12/2024 : Le thème probable est tombé : « cycles et boucles ». Je n’ai donc plus d’idée pour mon sujet. Je ne sais pas comment le relier au thème, et M. Fourcade m’a dit que c’était un sujet trop ambitieux. Il m’a cependant quand même laissé le choix et M. Boutin m’avait dit que c’était faisable.

15/01/2025 : J’ai récupéré la boite de vitesses et l’ai montée dans le labo. J’ai pris quelques photos et ai expérimenté pour comprendre le fonctionnement de la boite. C’est une boite JB1 de Twingo à 5 rapports + 1 marche arrière. J’ai réussi à trouver un PDF avec énormément d’informations très utiles, mais il me manque quelques références pour trouver quel modèle de boite je possède. J’ai découvert que le différentiel est intégré dans la boite, je dois donc le souder, et j’ai peut-être trouvé comment faire avec l’aide de Simon Bordes. Le fait d’avoir le différentiel intégré dans la boite, cela va dégrader le rendement final, et il faudra bien le prendre en compte dans les données finales.

09/02/2025 : Avec l’aide de Simon Bordes, j’ai conçu un système permettant de bloquer le différentiel de la boite de vitesses.

12/03/2025 : Après une grosse discussion avec M. Fourcade et M. Sacquard, j’ai décidé d’abandonner mon sujet sur la boite de vitesses car beaucoup trop ambitieux, et nous n’avons pas les moyens de mesurer des rendements aussi précisément. Ils ont raison, il vaut mieux arrêter maintenant plutôt que d’arrêter en fin de deuxième année.

26/03/2025 : Après beaucoup de recherches, j’ai trouvé un sujet (validé par M. Fourcade) : le régulateur de vitesse adaptatif et sa boucle de rétroaction PID. J’ai commencé à me renseigner et j’ai trouvé des papiers sur l’ACC (Adaptive Cruise Control). Je regarde également pour acheter une ou plusieurs voitures télécommandées, pour éventuellement faire la suiveuse et la meneuse, et des Arduino ainsi que des capteurs, cependant cela devrait revenir très cher, à voir la solution (travail cet été ?).

07/05/2025 : J’ai commencé une simulation Matlab Simulink en essayant de modéliser le système. J’avance très lentement pour prendre le temps de comprendre tout, mais c’est assez complexe.

14/05/2025 : J’ai commencé à coder une simulation Python, cependant elle ne mène pour l’instant pas très loin, car j’ai passé la séance à me renseigner sur les aspects mathématiques et techniques de comment transcrire le régulateur PID en Python. Ceci est une étape me permettant de comprendre comment fonctionne un régulateur PID mais aussi me permettra de le coder plus facilement sur Arduino.

19/08/2025 : J’ai reçu la voiture télécommandée et l’Arduino et j’ai démonté la voiture et commencé le design d’un support pour l’Arduino adapté.

20/08/2025 : J’ai fini le design du support, l’ai imprimé et quelques mesures sont à revoir. J’ai retravaillé le support et l’ai imprimé. Je devrais bientôt recevoir tous les capteurs dont j’ai besoin. J’ai commandé en plus des ponts en H L298N pour contrôler le moteur brushed RC390.

22/08/2025 : J’ai commencé le code pour l’Arduino, je commence sans boucle de rétroaction PID car je n’ai pas encore tout compris.

01/09/2025 : J’ai tout reçu et ai continué à faire les supports.

06/09/2025 : J’ai continué à faire les supports, et j’ai commencé le câblage de l’Arduino avec tous les capteurs.

08/09/2025 : J’ai enfin réussi à avoir des prototypes de supports corrects et j’ai commencé le montage de l’Arduino et des capteurs sur la voiture, j’ai commencé les soudures et le câblage « final. »

12/09/2025 : J’ai continué la soudure mais malheureusement, de l’étain a atterri sur des soudures d’origine de l’Arduino et la carte a cramée. Je vais donc en racheter une.

Notes :

Une boite de vitesses est composée de 2 arbres, un primaire et un secondaire. L’arbre primaire est relié à l’embrayage et tourne donc à la même vitesse que le moteur. L’arbre secondaire est parallèle à l’arbre primaire et est relié à l’arbre de sortie de boite. L’arbre primaire possède des pignons solidaires, qui sont en contact avec d’autres pignons fous en liaison pivot avec l’arbre secondaire. Des baladeurs, composé de synchronisateurs et de crabots, sont en liaison glissière avec l’arbre secondaire, et donc tourne à la même vitesse que celui-ci. Lorsque le conducteur sélectionne la 1ère vitesse, le baladeur situé entre les pignons correspondant aux 1ère et 2e vitesses se déplace vers le pignon 1 et le synchroniseur permet, par friction conique, de synchroniser les vitesses de l’arbre secondaire et du pignon fou 1, permettant à la vitesse du moteur d’être réduite et transmise au différentiel. Cela fonctionne exactement pareil pour toutes les vitesses, avec des rapports différents, sauf la marche arrière. Lorsque le conducteur sélectionne la marche arrière, un baladeur en liaison pivot avec un pignon et en liaison glissière avec le bâti se déplace pour aller positionner son pignon entre un pignon solidaire à l’arbre primaire et un autre pignon solidaire de l’arbre secondaire.

Il y a, entre le moteur et la boite de vitesses, un embrayage effectuant la transmission de la puissance du moteur à la boite de vitesses. L’embrayage est composé d’un volant moteur, tournant à la même vitesse que le moteur, d’un disque d’embrayage, relié à l’arbre primaire de la boite, d’une butée d’embrayage, d’un plateau de pression et de ressorts. Lorsque le conducteur débraye, les ressorts sont comprimés par la butée d’embrayage, et ils lèvent le plateau de pression ce qui décolle le disque d’embrayage du volant moteur, cassant la liaison entre les deux. Lorsque le conducteur embraye, il relâche progressivement la pédale, donc la butée recule progressivement et lâche lentement les ressorts qui relâche le plateau de pression, qui appuie le disque d’embrayage sur le volant moteur, et, lorsque la phase de glissement (ou patinage) est terminée, le volant moteur transmet toute sa puissance à travers le disque d’embrayage par friction.

Pour effectuer des mesures, on peut connecter un moteur DC en entrée et un autre en sortie de boite. On peut mesurer la vitesse entrante et sortante grâce à un capteur à effet Hall et le couple entrant grâce à l’intensité consommée par le moteur en entrée. Le couple sortant peut être mesuré grâce au courant généré par le moteur en sortie.

On peut effectuer des expérimentations sur plusieurs types de lubrifications : sans rien, avec de l’eau, avec l’huile recommandée (75w80), de l’huile plus épaisse (70w) et de l’huile plus fine (80w140), en testant le tout au démarrage à froid, et en fonctionnement à chaud.

Contacts potentiels donnés par M. Boutin :

- Valentin Boissout – IAC Partner - Manager dans les performances industrielles : valentin.boissout@gadz.org
- Lucas Peyronie – Alpine – Performances pneumatiques (il a travaillé dans la transmission pour un sous-traitant de BMW, Porsche et Bugatti) : lucas.peyronie.19@gmail.com

CHANGEMENT DE SUJET

## REYNAUD Emile

Le 13/05/2025 à 21:27:37. Bibliographie : 242 mots. Problématique : 20 mots. Ancrage au thème : 21 mots. Motivation du choix : 30 mots.

# Régulateur de vitesse adaptatif et boucle de rétroaction PID

POSITIONNEMENT THÉMATIQUE : Sciences industrielles
MOTS-CLÉS/KEYWORDS : Adaptative Cruise Control ; boucle de correction PID ; régulation de vitesse

BIBLIOGRAPHIE COMMENTÉE :
Saputro, J. S. et al. Design of an Adaptive Cruise Control System using PID Control Method on Electric Vehicle Prototypes, IEEE, 2023.
Cet article présente une mise en œuvre concrète d’un système de régulateur adaptatif (ACC) sur un prototype de véhicule électrique. L’utilisation de capteurs LiDAR et d’un algorithme PID permet une adaptation dynamique de la vitesse en fonction de la distance au véhicule précédent. L'étude apporte des données quantitatives utiles (temps de réponse, précision, distance de sécurité) et m’a permis de comprendre les limites physiques et électroniques d’un ACC en environnement réel.
Saravanan, G. et al. Red Panda Optimization Algorithm-Based PID Controller Design for Automobile Cruise Control System, IEEE, 2024.
Ce papier propose une amélioration des performances d’un régulateur PID via un algorithme d’optimisation inspiré de la nature : le Red Panda Optimization. Cette méthode optimise les gains du PID pour réduire le temps de montée, le dépassement et le temps de stabilisation. J’ai utilisé cette source pour approfondir les techniques avancées de réglage PID et imaginer des solutions coopératives entre véhicules grâce à une régulation plus fine et adaptative.
Kukkala, V. K. et al. Advanced Driver-Assistance Systems: A Path Toward Autonomous Vehicles, IEEE Consumer Electronics Magazine, 2018.
Un article de référence qui replace l’ACC dans le cadre plus large des systèmes avancés d’aide à la conduite (ADAS). Il m’a aidé à comprendre l’évolution vers les véhicules autonomes et les interactions potentielles entre plusieurs ACC, condition indispensable à une régulation harmonieuse en trafic dense.

RÉFÉRENCES BIBLIOGRAPHIQUES :
[1] : Saravanan G, Pazhanimuthu C, Sathish Kumar D, Lalitha B, Senthilkumar M, Kannan E Red Panda Optimization Algorithm-Based PID Controller Design for Automobile Cruise Control System ICSSEECC 2024 ; https://ieeexplore-ieee-org.ezproxy.unilim.fr/document/10649422 0 mots.
[2] : Joko Slamet Saputro, M. Shafiy Widi Kresno Wibisono, Joko Hariyono, Miftahul Anwar, Warindi DESIGN OF AN ADAPTIVE CRUISE CONTROL SYSTEM USING PID CONTROL METHOD ON ELECTRIC VEHICLE PROTOTYPES ICAMIMIA 2023 ; https://ieeexplore-ieee-org.ezproxy.unilim.fr/document/10427856 0 mots.
[3] : Vipin Kumar Kukkala, Jordan Tunnell, Sudeep Pasricha, Thomas Bradley Advanced Driver-Assistance Systems: A path toward autonomous vehicles. IEEE Consumer Electronics Magazine, 2018 ; https://ieeexplore-ieee-org.ezproxy.unilim.fr/document/8429957 0 mots.

PROBLÉMATIQUE RETENUE :
Comment les régulateurs de vitesse adaptatif fonctionnent-ils et comment adapter ce fonctionnement pour un usage en harmonie entre véhicules ?

ANCRAGE AU THÈME "Cycles, boucles" :
Cette thématique est liée au thème par la boucle d'asservissements et notamment la boucle de correction proportionnel-intégral-dérivateur (PID).

MOTIVATION DU CHOIX DE L'ÉTUDE :
J'ai toujours aimé l'automobile et les systèmes embarqués, mon choix s'est donc posé sur un des systèmes qui me fascinait le plus : le régulateur de vitesse adaptatif.

Bibliographie commentée v2 :

Le régulateur de vitesse est une technologie aujourd’hui omniprésente dans les véhicules personnels. Depuis une dizaine d’années, ce régulateur a été amélioré et une version dite adaptative est aujourd’hui largement répandue. Ce régulateur de vitesse adaptatif, ou AAC, acronyme de Adaptive Cruise Control, est une technologie faisant partie d’un ensemble de systèmes d’aides à la conduite, ou ADAS, acronyme de Advanced Driver-Assistance Systems [3]. Un AAC est un système permettant de réguler la vitesse du véhicule à partir d’une vitesse choisie par l’utilisateur. Le régulateur de système adaptatif rajoute, en plus de cette fonctionnalité, la possibilité de garder une distance de sécurité entre le véhicule qui précède. Donc lorsque ce dernier ralentit, la voiture équipée de l’AAC ralentit automatiquement. De plus, le régulateur calcule la distance de sécurité selon la vitesse du véhicule, mais détermine également une distance minimale à laquelle la voiture peut être du véhicule qui précède, et lorsqu’elle se trouve à une distance inférieure à celle-ci, le véhicule doit effectuer un freinage d’urgence. Cependant lorsque la voiture équipée de l’AAC se trouve entre la distance minimale et la distance de sécurité, la vitesse sera diminuée ou augmentée en douceur, pour ne pas perturber le confort du conducteur et des passagers. Ce système doit posséder une boucle d’asservissements pour pouvoir garder une distance constante sans trop de variations. Cette boucle, comme beaucoup de systèmes embarqués en voiture, est équipé d’un correcteur PID (proportionnel-intégral-dérivateur) [1]. Celui-ci permet une correction efficace avec très peu ou pas de dépassements et pas d’oscillations. Pour obtenir les meilleurs paramètres PID, un réglage doit être effectué. Ce réglage peut être fait via plusieurs algorithmes, comme le Red Panda Optimization Algorithm [2]. Ce dernier permet de trouver les paramètres PID optimaux. Cependant, ce dernier est très complexe, et beaucoup de simples expériences ou simulations peuvent permettre de déterminer les paramètres optimaux.

Mot de passe : cycleboucle26

PID : proportionnel-intégral-dérivé. Régulateur utilisant l’erreur (à définir si demandé) en entrée et contrôlant ici le moteur électrique pour minimiser cette erreur. Associe stabilité, précision et rapidité dans un magnifique compromis.

Kp : multiplie l’erreur par un coef ce qui rend la sortie proportionnelle à l’erreur (si erreur ++, correction ++)

Ki : vise à éliminer l’erreur persistante en accumulant les erreurs passées et en les intégrant dans le temps -> amène le système plus près de la consigne progressivement

Kd : action prédictive permettant de réagir aux futurs évènements à partir des tendances observées.

M. Boutin m’avait dit de trouver un moyen de corriger la trajectoire, mais je ne rajouterai pas de tel système car ça me rajoute un énorme problème en plus qui est assez difficile à résoudre. De plus, un ACC dans une voiture ne corrige pas la trajectoire, le conducteur doit quand même s’en occuper, donc je laisserai le module radio de la voiture télécommandée, mais il sera uniquement connecté au servomoteur de direction et l’utilisateur devra contrôler la trajectoire manuellement.

TIPE PTSI 2026

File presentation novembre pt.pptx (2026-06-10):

## Régulateur de vitesse adaptatif et boucle de rétroaction PID

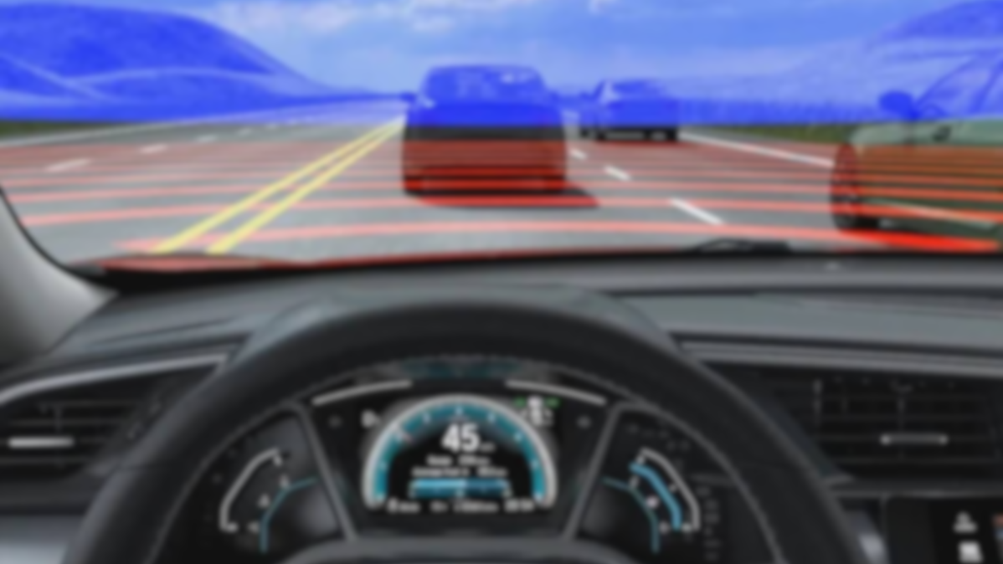
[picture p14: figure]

Problématique :
Comment un régulateur de vitesse adaptatif fonctionne-t-il et comment sa boucle de correction se comporte-t-elle ?

## Ancrage au thème “Cycles et boucles“

- Étude de la boucle de correction d’un régulateur de vitesse adaptatif

## Maquette

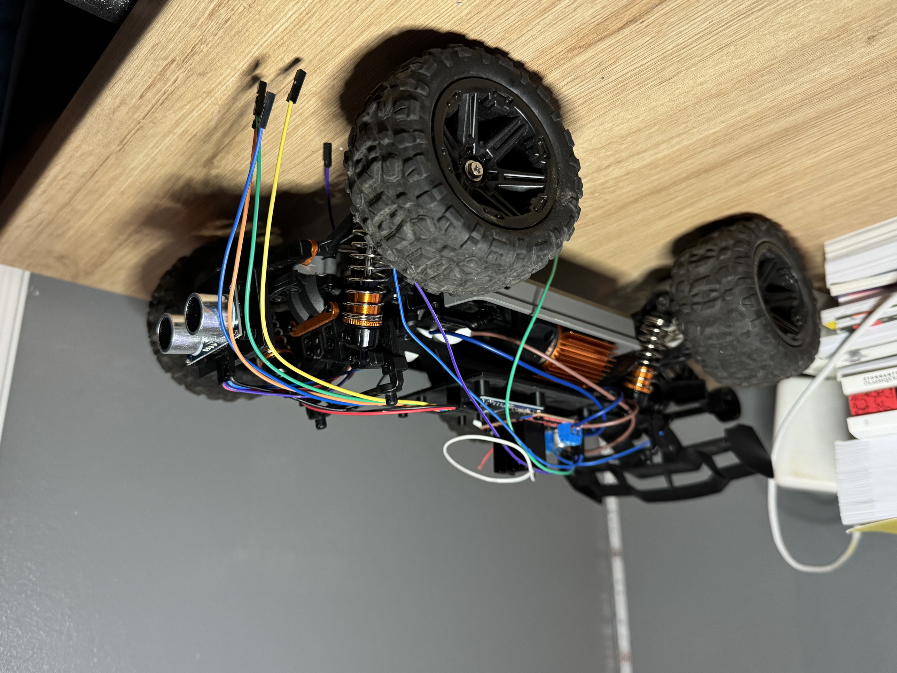
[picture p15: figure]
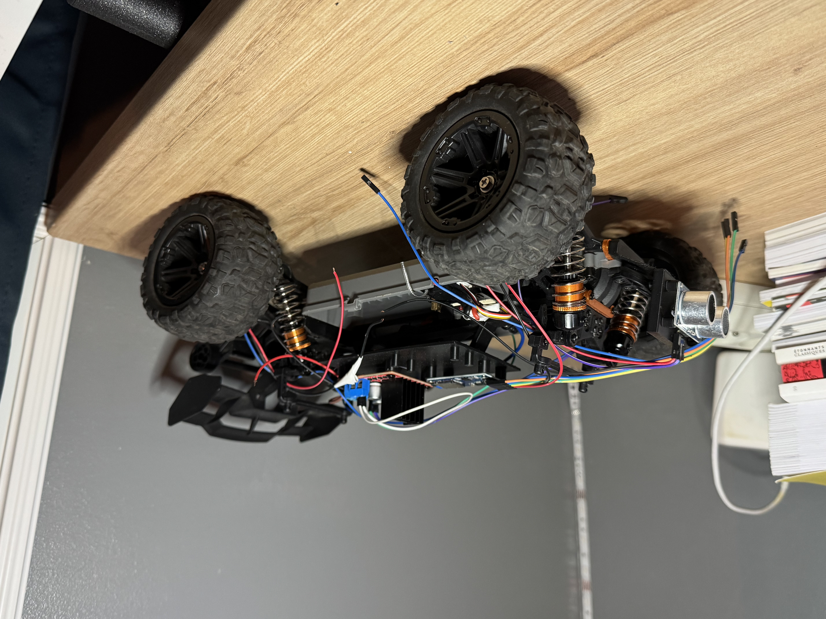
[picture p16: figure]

## Expériences prévues

Protocole : vitesse fixée à 5 km/h, une planche mobile sera placée devant la maquette
Expériences :
- Test de la maquette avec un correcteur Proportionnel
- Idem avec un correcteur Proportionnel Intégral (PI)
- Idem avec un correcteur Proportionnel Dérivé (PD)
- Idem avec un correcteur Proportionnel Intégral Dérivé (PID)

## Bibliographie

- Advanced Driver-Assistance Systems: A path toward autonomous vehicles. (Vipin Kumar Kukkala, Jordan Tunnell, Sudeep Pasricha, Thomas Bradley)
- DESIGN OF AN ADAPTIVE CRUISE CONTROL SYSTEM USING PID CONTROL METHOD ON ELECTRIC VEHICLE PROTOTYPES (Joko Slamet Saputro, M. Shafiy Widi Kresno Wibisono, Joko Hariyono, Miftahul Anwar, Warindi)
- Red Panda Optimization Algorithm-Based PID Controller Design for Automobile Cruise Control System (Saravanan G, Pazhanimuthu C, Sathish Kumar D, Lalitha B, Senthilkumar M, Kannan E)

## Perspectives

Ajouter une deuxième maquette, qui sera placée devant la maquette équipée du régulateur, pour améliorer le modèle.

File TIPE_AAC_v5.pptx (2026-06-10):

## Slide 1

Régulateur de vitesse adaptatif
et boucle de rétroaction PID

Comment un régulateur de vitesse adaptatif fonctionne-t-il,
et comment sa boucle de correction PID se comporte-t-elle ?

📷 Photo
maquette

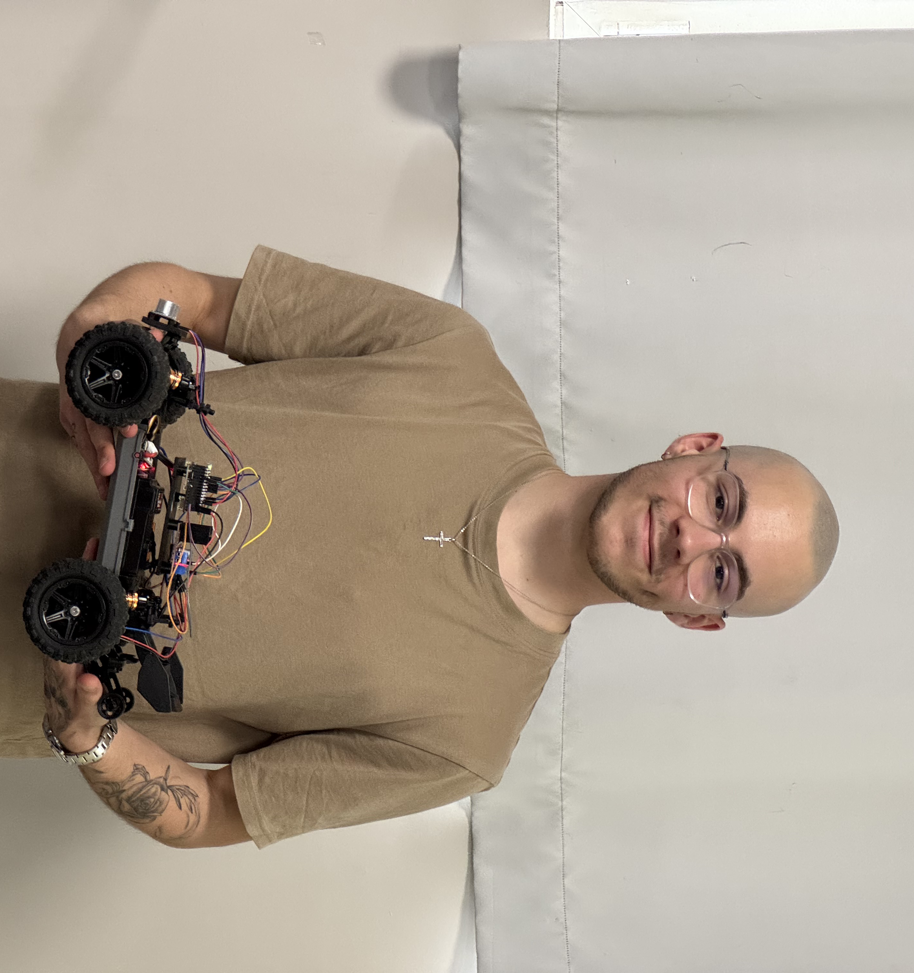
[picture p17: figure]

TIPE — Thème : Cycles et boucles | Filière PT

N° candidat : 40296

1 / 20

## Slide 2

Ancrage au thème et problématique

Thème : Cycles et boucles

- Boucle de rétroaction : mesure → correcteur → actionneur
- Cycles de correction répétés toutes les 50 ms
- Itérations de réglage P → PI → PD → PID

Problématique

Comment un régulateur de vitesse adaptatif fonctionne-t-il,
et comment sa boucle de correction PID se comporte-t-elle ?

Schéma-bloc boucle fermée (notation SI)

Chaîne de retour — mesure v(t)

U_FF

Vc(t)
0.7 m/s

+
−

ε(t)

C(s)
Correcteur PID

Σ

G(s)
K/(τs+1)

Voiture
H=1

v(t)

Capteur Hall
(méthode période)

2 / 20

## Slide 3

Maquette expérimentale

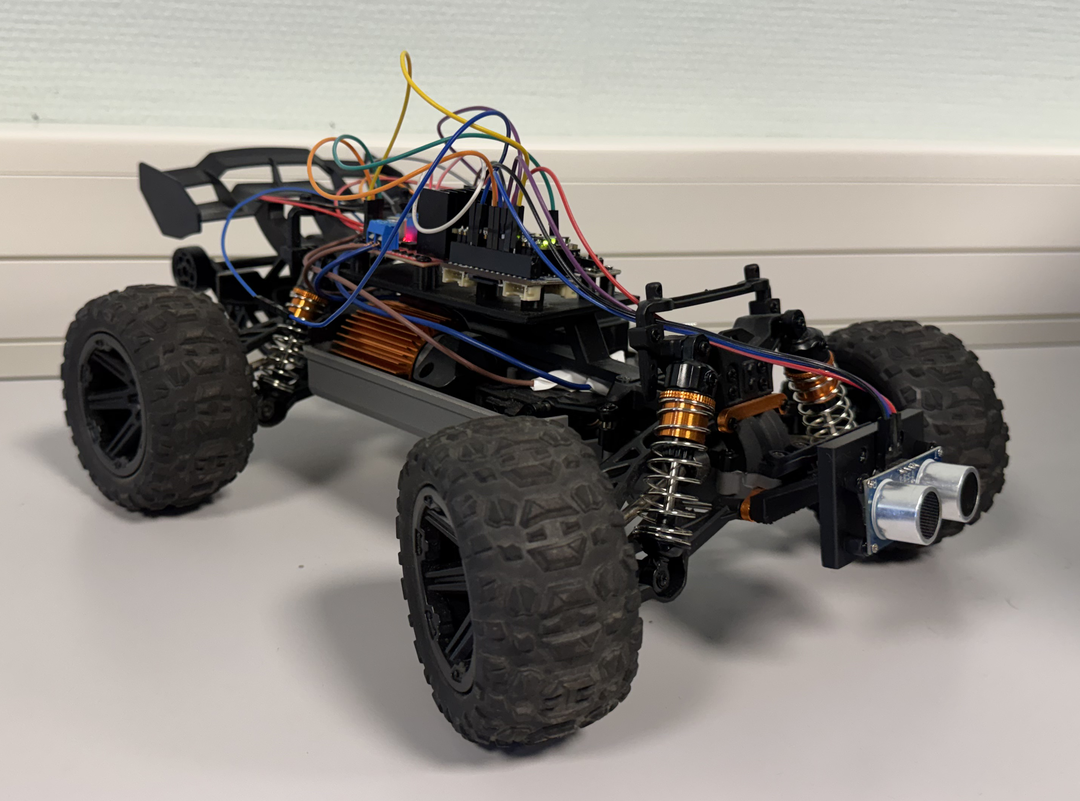
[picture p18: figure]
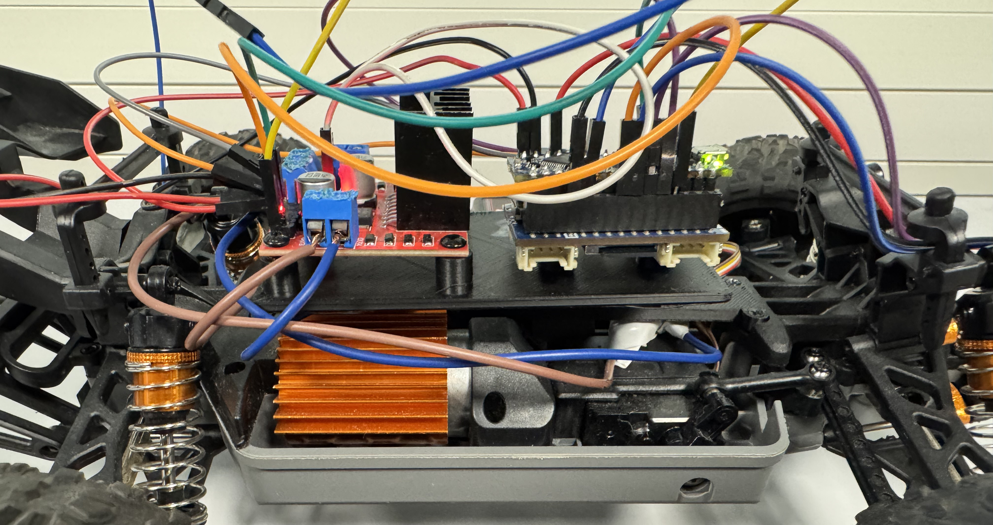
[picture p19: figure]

Composants

- Arduino Nano Every + shield ASX00061
- Pont en H L298N → moteur brushed RC390
- Capteur ultrason HC-SR04 (distance obstacle)
- Capteur Hall + 3 aimants néodyme (vitesse)
- Carte microSD → log CSV temps réel

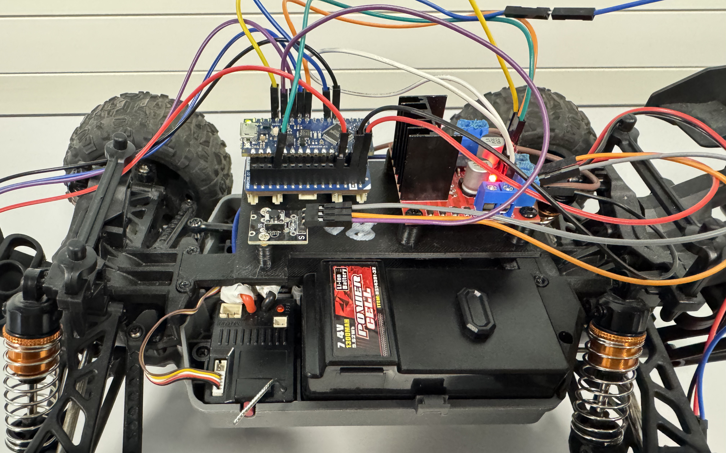
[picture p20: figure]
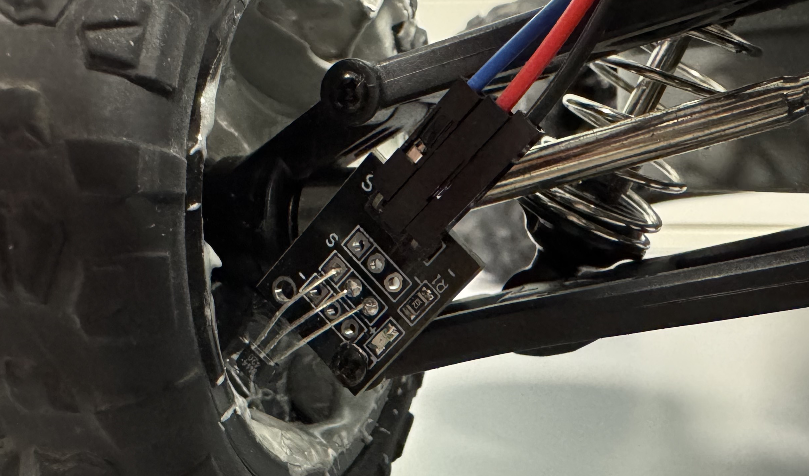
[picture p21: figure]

3 / 20

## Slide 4

Identification du moteur — Pourquoi et comment ?

Pourquoi identifier le moteur ?

- Le PID seul échoue : à consigne atteinte, ε→0 donc u_PID→0, le moteur s'arrête (zone morte sous 76/255)
- Necéssité d’un feedforward, donc besoin d’identifier le moteur

Modèle 1er ordre

τ · dv/dt + v(t) = K · u(t)

Réponse à échelon u=U₀ :
v(t) = K·U₀·(1 − e^(−t/τ))

Lecture graphique

K = v∞/U₀ (vitesse de régime / commande)
τ = t tel que v(t) = 63,2 % × v∞
(propriété : 1−e⁻¹ ≈ 0,632)

Protocole

- 9 échelons PWM 40→240, 3 s chacun
- Mesure v∞ (palier stable) et τ (passage à 63,2%)
- K = v∞/U₀ validé sur tous les échelons

Résultats identifiés

1,4 m/s

gain statique

250 ms

constante de temps

0,30 → 76/255

PWM minimal

→ U_FF = (0.7/1.4+0.3)×255 = 204 PWM

K

τ

Seuil

4 / 20

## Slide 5

Mesure de vitesse — méthode fréquencemétrique

Principe

- Comptage δ d'impulsions Hall sur T=50 ms
- 3 aimants → p=πD/N≈0,0873 m
- v = (δ/N)×C/T δ ∈ ℕ

Incertitude

- Δδ = ±1 → Δv = p/T = constante
- Δv = 0,2608/(3×0,050) ≈ 1,74 m/s
- À Vc=0,70 m/s : Δv/v = 249 %
- Inutilisable seule pour le terme D


Incertitude Δv vs vitesse — méthode fréquencemétrique

5 / 20

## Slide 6

Mesure de vitesse — méthode période

Principe

- Mesure du temps τ entre 2 fronts Hall (ISR)
- Résolution micros() : 4 µs → Δτ=4 µs
- v = p/τ avec p=0,0873 m

Incertitude

- Δv ≈ v×Δp/p (terme géométrique dominant)
- Δp/p = 2 mm/87,3 mm ≈ 2,3 % relatif constant
- À v=0,70 m/s : Δv ≈ 0,016 m/s
- ×155 plus précise que fréquencemétrique


Incertitude Δv vs vitesse — méthode période

6 / 20

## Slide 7

Architecture du régulateur — Feedforward + PID

Problème du PID pur

- Seuil démarrage : 76/255 — zone morte
- En régime : ε→0 ⟹ u_PID→0
- Moteur sous le seuil → roue libre → re-kick
- Oscillation infinie sans terme constant

Solution

u(t) = U_FF + Kp·ε + Ki·∫ε dt + Kd·(dε/dt)

U_FF = (Vc/K+seuil)×255 = 204 PWM

FF → maintient la vitesse de régime
PID → corrige les écarts résiduels
Mode distance (ACC v19) : cmd = cmd_vitesse − 600 × max(0, Dc − d)

Schéma-bloc (notation SI)

Chaîne de retour — mesure v(t)

U_FF

Vc
0.7m/s

+
−

ε

C(s)
PID

Σ

G(s)
K/(τs+1)

Voiture
H=1

v(t)

Capteur Hall
(méthode période)

7 / 20

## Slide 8

Protocole expérimental — Acquisition des courbes P / PI / PD / PID

Démarrage
0–3 s

Mode vitesse
3–12 s

Mode distance
(ACC actif)
12–27 s

Retour vitesse
27–35 s

35 s

0 s

① Démarrage (0-3s)

Kick-start moteur
PWM selon correcteur :
P / PI : 209 PWM / 250 ms
PD : 255 PWM / 800 ms
PID : 153 PWM / 1 000 ms
Objectif
Franchir la zone morte
(seuil = 76 PWM = 0,30 × 255)
Mesure
v_mesurée < 0,05 m/s → roue
quasi arrêtée avant kick

3 s

② Mode vitesse (3-12s)

Consigne : Vc = 0,70 m/s
Aucun obstacle (d = −1)
Critères observés
Erreur statique en régime
Dépassement au démarrage
tr5% = temps pour entrer
dans la bande ±5 % de Vc
Oscillations de commande
Durée intentionnelle : 9 s
Laisse le PI converger

12 s

③ Mode distance (12-27s)

t = 12–15 s : approche
Obstacle : 0,60 → 0,15 m
d < Dc = 0,30 m → freinage
t = 15–21 s : proximité
Obstacle maintenu à 0,15 m
Freinage : 600×(0,30−0,15)
= 90 PWM de réduction
t = 21–27 s : éloignement
Obstacle : 0,15 → 1,20 m
d > Dc → freinage = 0
Voiture réaccélère vers Vc

27 s

Retour vitesse (27-35s)

Obstacle hors portée (d > 1,2 m)
Retour automatique en mode ②
Validation
Comportement identique à ②
Vérifie la répétabilité
et la stabilité au retour
Intégrale (PI / PID)
Gel pendant freinage ACC
→ pas de windup
→ réponse propre au retour
à la vitesse de croisière

Paramètres communs : Vc = 0,70 m/s | Dc = 0,30 m | K_brake = 600 PWM/m | Boucle = 50 ms (20 Hz) | Log CSV = 10 Hz | U_FF = 204 PWM | Bruit Hall = σ 0,025 m/s + composante 0,012 m/s @ 8 Hz

8 / 20

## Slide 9

Correcteur P — Résultats expérimentaux


Protocole : démarrage → régulation vitesse (Vc=0.7 m/s) → obstacle → retour vitesse

9 / 20

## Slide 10

Correcteur P — Analyse

Observations positives

- Démarrage efficace : kick-start (209 PWM, 250 ms) pour franchir le seuil moteur
- Commande stable à ~170–180 PWM en régime sans obstacle

Limites observées

- Erreur statique −0,23 m/s (33 %) : structurelle sans terme intégral
- Commande saccadée en mode distance (bruit amplifié par Kp)
- tr5% : N/A — la vitesse ne converge jamais vers Vc

Bilan

L'erreur statique de 33 % est irréductible sans terme intégral. Sert de référence comparative.

10 / 20

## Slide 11

Correcteur PI — Résultats expérimentaux


Protocole : démarrage → régulation vitesse (Vc=0.7 m/s) → obstacle → retour vitesse

11 / 20

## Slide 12

Correcteur PI — Analyse

Observations positives

- Erreur statique → 0 : Ki=60 compense l’erreur (visible sur la courbe)
- Aucun dépassement : système très amorti, convergence monotone
- Transition vers mode distance propre : intégrale continue, pas de saut de commande

Limites observées

- tr5% ≈ 7,5 s — le plus lent des 4 : voiture parcourt >5 m avant d'atteindre Vc
- Kp=15 volontairement faible → peu réactif aux perturbations soudaines
- Réinitialisation de l'intégrale au kick → convergence repart à zéro après démarrage

Bilan

Le PI atteint la précision au prix de la rapidité. tr5% = 7,5 s est rédhibitoire en conditions réelles — à 0,70 m/s, la voiture parcourt 5 mètres avant d'être à vitesse.

12 / 20

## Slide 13

Correcteur PD — Résultats expérimentaux


Protocole : démarrage → régulation vitesse (Vc=0.7 m/s) → obstacle → retour vitesse

13 / 20

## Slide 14

Correcteur PD — Analyse

Observations positives

- tr5% ≈ 1,5 s — le plus rapide des 4 correcteurs
- Dépassement 14 % clairement visible

Limites observées

- Erreur statique −0,13 m/s (19 %) : irréductible sans terme intégral
- Dépassement 14 % > norme standard 5 % — non conforme

Bilan

Le PD est rapide mais imprécis. Dépassement 14 % dépasse la norme de 5 %. Sans intégrale, l'erreur statique de 19 % persiste indéfiniment. Bon transitoire, mauvais état final.

14 / 20

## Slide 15

Correcteur PID — Résultats expérimentaux


Protocole : démarrage → régulation vitesse (Vc=0.7 m/s) → obstacle → retour vitesse

15 / 20

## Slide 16

Correcteur PID — Analyse

Observations positives

- Erreur statique < 1 % (−0,01 m/s) : intégrale (Ki=40) élimine l’erreur en ~5 s
- Dépassement 4,8 % < 5 % : conforme à la norme standard industrielle
- tr5% ≈ 4 s : bon compromis rapidité / stabilité entre PI (7,5 s) et PD (1,5 s)
- Mode distance ACC propre : maintien de Vc puis freinage proportionnel à la proximité

Limites observées

- Réglage plus complexe : 3 paramètres interdépendants (Kp, Ki, Kd)
- Anti-windup nécessaire : intégrale gelée pendant le freinage en mode distance
- Terme D sensible au bruit Hall (atténué par dérivée sur mesure)

Bilan

Seul le PID satisfait simultanément les 3 critères : erreur < 1 %, dépassement 4,8 % ≤ 5 %, tr5% = 4 s. L'architecture FF + PID constitue la solution optimale.

16 / 20

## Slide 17

Comparaison des correcteurs

Correcteur | Erreur statique | Dépassement | Robustesse bruit | Complexité | Verdict
P | −0,23 m/s (33 %) | 0 % | Bonne | Simple | ✗ Erreur résiduelle
PI | → 0 (en ~8 s) | 0 % | Moyenne | Moyenne | ⚠ Lent (tr5%=7,5 s)
PD | −0,13 m/s (19 %) | 14 % > 5 % | Faible | Moyenne | ✗ Hors norme
PID | < 1 % (≈ 0) | 4,8 % ≤ 5 % | Faible | Complexe | ✓✓ Optimal

Observation clé

- Le PID+FF est le seul à satisfaire les 3 critères : erreur < 1 %, dépassement 4,8 % ≤ 5 %,
tr5% = 4 s. Mode distance : freinage seul sans accélération vers l'obstacle.

Limites de la comparaison

- K varie avec la charge batterie → U_FF imprécis → biais systématique sur toutes les expériences
- 3 aimants : Δv_periode=23,01% — oscillations résiduelles ±0,10 m/s liées à la zone morte (irréductibles sans changer le matériel)

17 / 20

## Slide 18

Limites et perspectives

Limites matérielles

- 3 aimants : Δv_freq=1,74 m/s (249% à 0,70 m/s)
- K varie avec batterie → re-identification nécessaire
- HC-SR04 : fausses détections en extérieur
- Zone morte 76/255 → oscillations irréductibles

Perspectives

- 12 aimants → Δv_freq divisé par 4
- Encodeur optique → résolution µm
- 2e maquette → obstacle mobile réaliste
- Re-identification auto (K adaptatif)

18 / 20

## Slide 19

Conclusion

Régulation vitesse et distance à obstacle sur voiture RC

Maquette fonctionnelle

1er ordre : K=1,4 m/s, τ=250 ms, seuil=76/255

Identification moteur

Méthode période ×155 plus précise que fréquencemétrique à 0,70 m/s

Mesure de vitesse

U_FF indispensable — PID corrige les écarts résiduels

Architecture FF+PID

PID = meilleur compromis

Comparaison P/PI/PD/PID

Boucle de rétroaction → cycle de correction répété à chaque période 50 ms

Thème

19 / 20

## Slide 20

Bibliographie et annexe code

Références bibliographiques

[1] V.K. Kukkala, J. Tunnell, S. Pasricha, T. Bradley — "Advanced Driver-Assistance Systems: A Path Toward Autonomous Vehicles" — IEEE Consumer Electronics Magazine, vol. 7, n°5, pp. 18-25, 2018. DOI: 10.1109/MCE.2018.2828440

[2] J.E. Naranjo, F. Serradilla, F. Nashashibi — "Speed Control Optimization for Autonomous Vehicles with Metaheuristics" — Electronics 2020, 9, 551. DOI: 10.3390/electronics9040551

[3] Saravanan G et al. — "Red Panda Optimization Algorithm-Based PID Controller Design for Automobile Cruise Control System" — ICSSEECC 2024. DOI: 10.1109/ICSSEECC61126.2024.10649422

[4] J.S. Saputro et al. — "Design of an Adaptive Cruise Control System using PID Control Method on Electric Vehicle Prototypes" — ICAMIMIA 2023. DOI: 10.1109/ICAMIMIA60881.2023.10427856

Annexe code Arduino

Listings complets fournis sur support papier en double exemplaire. Modules : hallISR(), calculerVitessePeriode(), calculerCorrecteur() PID, calculerCommandeMoteur() kick+rampe, appliquerCommande() zone morte, lireDistance(), loop().

20 / 20

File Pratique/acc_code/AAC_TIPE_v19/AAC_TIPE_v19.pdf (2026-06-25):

1 /*
2 * RÉGULATEUR DE VITESSE ADAPTATIF ET SA BOUCLE DE RÉTROACTION PID 3 * TIPE Par Emile Reynaud
4 */
5
6 // Définition de 4 constantes numériques au lieu d'avoir des str 7 #define CORR_P 1 // correcteur proportionnel seul
8 #define CORR_PI 2 // correcteur proportionnel + intégral
9 #define CORR_PD 3 // correcteur proportionnel + dérivé
10 #define CORR_PID 4 // correcteur proportionnel + intégral + dérivé 11
12 // Choix du correcteur en décommentant une seule ligne
13 // #define CORRECTEUR CORR_P
14 // #define CORRECTEUR CORR_PI
15 // #define CORRECTEUR CORR_PD
16 #define CORRECTEUR CORR_PID
17
18 // Définition des bonnes constantes en fonction du correcteur 19 #if CORRECTEUR == CORR_P
20 | #define Kp_VAL 60.0f
21 | #define Ki_VAL 0.0f
22 | #define Kd_VAL 0.0f
23 | #define USE_I 0 // activation ou non de l'intégrale
24 | #define USE_D 0 // idem pour la dérivée
25 | #define MODE_STR "P" // label pour logs
26 | #define KICK_PWM_VAL 209 // PWM du kick
27 | #define KICK_DUREE_MS_VAL 250 // durée du kick
28
29 #elif CORRECTEUR == CORR_PI
30 | #define Kp_VAL 15.0f
31 | #define Ki_VAL 60.0f
32 | #define Kd_VAL 0.0f
33 | #define USE_I 1
34 | #define USE_D 0
35 | #define MODE_STR "PI"
36 | #define KICK_PWM_VAL 209
37 | #define KICK_DUREE_MS_VAL 250
38
39 #elif CORRECTEUR == CORR_PD
40 | #define Kp_VAL 350.0f
41 | #define Ki_VAL 0.0f
42 | #define Kd_VAL 10.0f
43 | #define USE_I 0
44 | #define USE_D 1
45 | #define MODE_STR "PD"
46 | #define KICK_PWM_VAL 255
47 | #define KICK_DUREE_MS_VAL 800
48
49 #elif CORRECTEUR == CORR_PID
50 | #define Kp_VAL 80.0f
51 | #define Ki_VAL 40.0f
52 | #define Kd_VAL 8.0f
53 | #define USE_I 1
54 | #define USE_D 1
55 | #define MODE_STR "PID"
56 | #define KICK_PWM_VAL 153
57 | #define KICK_DUREE_MS_VAL 1000
58
59 #else
60 | // Si pas de correcteur valide, renvoie une erreur
61 | #error "Correcteur non défini — décommenter une ligne CORRECTEUR ci-dessus"
62 #endif
63
64 // Identification moteur
65 const float K_MOTEUR = 1.40f; // gain statique du moteur
66 const float SEUIL_DEMARRAGE = 0.30f; // commande minimale normalisée pour démarrer 67
68 // Déclaration de la variable du feedforward
69 // Calcul de cette dernière dans setup()
70 float FEEDFORWARD_PWM = 0.0f;
71
72 // Gain de freinage pour le mode distance
73 const float KP_BRAKE_PWM = 600.0f; // en PWM/m
74
75 // Pins Arduino
76 #define TRIG_PIN 7 // pin TRIG du capteur à ultrason 77 #define ECHO_PIN 6 // pin ECHO du capteur à ultrason 78 #define HALL_PIN 2 // pin SIG du capteur à effet Hall 79 #define ENB_PIN 9 // pin ENB du pont en H
80 #define IN3_PIN A0 // pin IN3 du pont en H
81 #define IN4_PIN 5 // pin IN4 du pont en H
82 #define SD_CS_PIN 4 // pin SD_CS de la carte microSD 83 #define BUTTON_PIN 8 // bouton démarrage programme
84
85 // Roue
86 const int DIAMETRE_MM = 83; // diamètre de la roue (mm)
87 const float PERIMETRE_M = 3.14159f * (float)DIAMETRE_MM / 1000.0f; // Périmètre de la roue (m) 88 const uint8_t NB_AIMANTS = 3; // nombre d'aimants
89
90 // Constantes de consigne
91 const float DIST_CONSIGNE_M = 0.30f; // distance de consigne (m) 92 const float VITESSE_CIBLE_MS = 0.70f; // vitesse de consigne (m/s) 93
94 // Constantes de sécurité
95 const float DIST_URGENCE_M = 0.06f; // distance freinage d'urgence
96 const float DIST_MAX_OBSTACLE_M = 1.20f; // distance max à laquelle un objet est détecté 97
98 // Limite de l'intégrale
99 const float INTEGRALE_MAX = 100.0f; // valeur maximale de l'intégral (en PWM)
100
101 // Constantes temporelles
102 const uint16_t CONTROL_PERIOD_MS = 50; // période de la boucle de contrôle
103 const uint16_t LOG_PERIOD_MS = 100; // période d'écriture sur la carte SD
6/25/26, 6:18 PM | /home/emilereynaud/Documents/dev/school/TIPE-PT-ACC/Pratique/acc_code/AAC_TIPE_v19/AAC_TIPE_v19.ino
file:///run/user/1000/doc/3fb3ac26/out.html | 1/8

104 const uint16_t DEBOUNCE_MS = 30; // durée de l'anti-rebond du bouton
105 const uint32_t ECHO_TIMEOUT_US = 12000UL; // timeout capteur à ultrason 106 const uint32_t HALL_TIMEOUT_US = 400000UL; // timeout capteur à effet Hall 107
108 // Constantes pour le kick start
109 const uint8_t KICK_PWM_C = KICK_PWM_VAL; // puissance du kick
110 const uint16_t KICK_DUREE_MS_C = KICK_DUREE_MS_VAL; // durée du kick (ms)
111 const float VITESSE_QUASI_NULLE_MS = 0.05f; // en dessous de cette vitesse, on considère la roue arrêtée 112 const float COMMANDE_MIN_DEMARRAGE = 3.0f; // commande minimale pour déclencher un kick (PWM)
113
114 // Zone morte
115 const float PWM_ZONE_MORTE = 76.0f;
116
117 // Rampe de commande (lissage asymétrique)
118 const float RAMPE_MONTEE_PAR_S = 350.0f; // PWM/s accélération 119 const float RAMPE_DESCENTE_PAR_S = 700.0f; // PWM/s décélération 120
121 // Bibliothèques
122 #include <SPI.h> // protocole SPI nécessaire pour la carte SD
123 #include <SD.h> // permet de lire/écrire sur la carte SD
124
125 // Variables volatiles (pour éviter que le programme les mettent en cache car elle sont constamment modifiées) 126 volatile uint32_t hallPulseCount = 0; // nombre d'impulsions Hall reçues
127 volatile uint32_t hallLastPulseTime_us = 0; // timestamp (microseconde) de la dernière impulsion Hall
128 volatile uint32_t hallPeriode_us = 0; // durée (microseconde) entre les deux dernières impulsions
129 volatile bool hallNouvelleImpulsion = false; // nouvelle impulsion ou non
130
131 // Variables de mesures
132 uint32_t lastHallCount = 0; // valeur de hallPulseCount au dernier cycle (méthode fréquencemétrique) 133 float vitesse_ms = 0.0f; // vitesse mesurée par méthode fréquencemétrique (m/s)
134 float vitesse_periode_ms = 0.0f; // vitesse mesurée par méthode période (m/s)
135
136 // Variables correcteur
137 float integrale = 0.0f; // accumulateur de l'intégrale (terme I du PI et PID) 138
139 // Dérivée calculée sur la mesure de vitesse
140 float vitessePeriodePrecedente = 0.0f; // vitesse_periode_ms du cycle précédent
141 bool deriveeInitialisee = false; // faux au démarrage, le premier cycle n'a pas de "précédent" 142
143 // Variables temporelles
144 uint32_t lastControlTime = 0; // timestamp du dernier contrôle (ms)
145 uint32_t lastLogTime = 0; // timestamp du dernier log SD (ms)
146 float derniereCommande = 0.0f; // PWM envoyée au moteur au dernier cycle 147
148 // Variables kick start
149 bool kickActif = false; // kick actif ou non
150 uint32_t kickDebutMs = 0; // timestamp (ms) du début du kick en cours 151 float commandeLisseePWM = 0.0f; // commande lissée par la rampe
152
153 // Variables carte SD
154 File logFile; // objet fichier ouvert sur la carte SD
155 bool sdOk = false; // carte SD initialisée et fichier ouvert ou non
156 char logFilename[13] = {0}; // nom du fichier CSV
157 uint16_t logLinesSinceFlush = 0; // compteur de lignes depuis le dernier flush() forcé
158 const uint8_t LOG_FLUSH_EVERY_N_LINES = 10; // on force un flush tous les 10 lignes pour ne pas perdre trop de données en cas de coupure 159
160 // Variables bouton
161 bool programmeActif = false; // régulateur actif ou non
162 const uint8_t BUTTON_ACTIVE_LEVEL = LOW; // état du pin quand le bouton est préssé 163 int buttonLastRawState = HIGH; // état lu au cycle précédent
164 int buttonStableState = HIGH; // état stable après anti-rebond
165 uint32_t lastButtonChangeTime = 0; // timestamp (ms) du dernier changement d'état brut 166
167 // Déclarations anticipées des fonctions
168 void appliquerCommande(float cmd);
169 void ecrireLog(float t_s, float dist_m, float erreur_m, uint8_t modeActuel);
170 void initSD();
171 void fermerLogSD();
172 float calculerCommandeMoteur(float cmdCorrecteur, float dt_s, bool urgence, bool interdireKick, uint32_t now); 173 float calculerCorrecteur(float erreur, float dt_s, bool reinitDerivee);
174
175
176 // Appelée à chaque passage d'aimant devant le capteur à effet Hall
177 void hallISR() {
178 uint32_t t_us = micros(); // timestamp en microseconde au passage de l'aimant 179
180 | // Anti-rebond
181 | if (hallLastPulseTime_us != 0 && (t_us - hallLastPulseTime_us < 20000UL)) return;
182
183 hallPulseCount++; // incrémenter le compteur total d'impulsions (méthode fréquencemétrique) 184
185 | if (hallLastPulseTime_us != 0) { // si pas la toute première impulsion
186 | hallPeriode_us = t_us - hallLastPulseTime_us; // durée entre les deux derniers aimants
187 | hallNouvelleImpulsion = true; // signalement nouvelle mesure dispo
188 | }
189
190 hallLastPulseTime_us = t_us; // mémoriser l'heure de cette impulsion pour le prochain calcul de période 191 }
192
193
194 // logique du bouton
195 void gererBoutonStartStop(uint32_t now) {
196 int rawState = digitalRead(BUTTON_PIN); // lire l'état du bouton (HIGH ou LOW) 197
198 | if (rawState != buttonLastRawState) { // état différent d'avant ?
199 | buttonLastRawState | = rawState; // mémoriser le nouvel état
200 | lastButtonChangeTime = now; // démarrer le chrono de l'anti-rebond
201 | }
202
203 | // si l'état reste le même pendant 30 ms, on valide l'état
204 | if ((now - lastButtonChangeTime) >= DEBOUNCE_MS && rawState != buttonStableState) {
205 | buttonStableState = rawState; // valider le nouvel état stable
206
207 if (buttonStableState == BUTTON_ACTIVE_LEVEL) { // bouton pressé ?

programmeActif = !programmeActif; // changer l'état du programme

if (programmeActif) { // on vient de démarrer ?
Serial.println(F("Bouton : START"));
if (!sdOk) initSD(); // ouvrir un nouveau fichier CSV si la SD n'est pas encore prête lastControlTime = now; // réinitialiser le timer de contrôle pour éviter un grand dt au premier cycle
214 | lastLogTime | = now; // réinitialiser le timer de log
} else { // on vient de s'arrêter ?
Serial.println(F("Bouton : STOP"));
arreterProgramme(); // appelle arreterProgramme() }
}
}
221 }

224 // remet toutes les variables d'état à zéro et ferme le fichier
225 void arreterProgramme() {
appliquerCommande(0.0f); // arrête le moteur
derniereCommande = 0.0f; // effacer la dernière commande mémorisée
integrale = 0.0f; // remettre l'intégrale à zéro
vitessePeriodePrecedente = 0.0f; // effacer la vitesse précédente (pour D) deriveeInitialisee = false; // indiquer que D doit être réinitialisé au prochain démarrage kickActif = false; // annuler le kick si il y en a un en cours
kickDebutMs = 0; // effacer le timestamp du kick
commandeLisseePWM = 0.0f; // remettre la rampe à zéro
fermerLogSD(); // fermeture du fichier

noInterrupts(); // désactiver les interruptions pour lire les variables volatiles sans conflit lastHallCount = hallPulseCount; // remettre le compteur fréquencemétrique à niveau hallLastPulseTime_us = 0; // effacer le timestamp Hall (forcer vitesse nulle pour après) hallPeriode_us = 0;// effacer la période Hall
hallNouvelleImpulsion = false; // effacer le drapeau de nouvelle impulsion interrupts(); // réactiver les interruptions

vitesse_periode_ms = 0.0f; // remettre la vitesse zéro
244 }

247 // mesure la distance jusqu'à l'obstacle devant la voiture
248 float lireDistance() {
digitalWrite(TRIG_PIN, LOW); // s'assurer que TRIG est bas avant de démarrer delayMicroseconds(2); // attendre 2 µs pour stabiliser le signal digitalWrite(TRIG_PIN, HIGH); // envoyer l'impulsion ultrason de début delayMicroseconds(10); // maintenir l'impulsion 10 µs (durée minimale pour le HC-SR04) digitalWrite(TRIG_PIN, LOW); // arrêter l'impulsion

// Mesurer la durée de l'écho, si timeout -> +2 m
long duree_us = pulseIn(ECHO_PIN, HIGH, ECHO_TIMEOUT_US);

if (duree_us == 0) return -1.0f; // si durée nulle : pas d'écho reçu (timeout ou obstacle hors portée)

// vitesse du son = 343 m/s = 0.000343 m/µs -> 0.0001715 m/µs (divisé par 2 car aller-retour)
float d = (float)duree_us * 0.0001715f;

if (d < 0.02f || d > 4.0f) return -1.0f; // valeur hors plage : rejetée

return d; // renvoie la distance en mètres
266 }

269 /* méthode fréquencemétrique de mesure de vitesse
compte les impulsions Hall sur 50 ms
peu précis à basse vitesse, très précis à haute vitesse
utilisé uniquement pour le log ici */
273 float calculerVitesse(uint32_t dt_ms) {
noInterrupts(); // bloquer les interruptions pour lire hallPulseCount (volatile) sans conflit uint32_t cnt = hallPulseCount; // récupérer le nombre d'impulsions totales
interrupts(); // rétablir les interruptions

uint32_t delta = cnt - lastHallCount; // nombre d'impulsions depuis le dernier appel lastHallCount = cnt; // mémoriser la valeur actuelle pour le prochain cycle

if (dt_ms == 0) return 0.0f; // protection contre division par zéro

// v = (nombre_de_tours * périmètre) / durée
// nombre_de_tours = delta / NB_AIMANTS (3 aimants = 3 impulsions par tour)
return (((float)delta / (float)NB_AIMANTS) * PERIMETRE_M) / ((float)dt_ms / 1000.0f); 286 }

289 /* méthode période de mesure de vitesse
mesure la durée entre deux fronts montants
plus précis à basse vitesse
| incertitude constante
filtre exponentiel asymétrique pour lisser sans retarder */ 294 float calculerVitessePeriode() {
// pas = périmètre / nb_aimants
static const float PAS_M = PERIMETRE_M / (float)NB_AIMANTS;

// Variation maximale physiquement possible en un cycle de 50 ms. // Au-delà, c'est un parasite (rebond mécanique) -> on rejette.
static const float DELTA_V_MAX = 0.8f; // m/s par cycle de 50 ms
| noInterrupts();
uint32_t derniereImp_us = hallLastPulseTime_us; // lire le timestamp de la dernière impulsion
| interrupts();

if (derniereImp_us == 0) return 0.0f; // pas encore d'impulsion reçue depuis le démarrage

// Si aucune impulsion depuis plus de 400 ms -> roue à l'arrêt
if ((micros() - derniereImp_us) > HALL_TIMEOUT_US) {
noInterrupts(); hallNouvelleImpulsion = false; interrupts(); // effacer le drapeau vitesse_periode_ms = 0.0f; // forcer la vitesse à zéro

312 | return 0.0f;
313 | }
314
315 | noInterrupts();
316 | uint32_t periode_us = hallPeriode_us; // copier la période mesurée par l'ISR
317 | hallNouvelleImpulsion = false; // effacer le drapeau de nouvelle mesure
318 | interrupts();
319
320 if (periode_us == 0) return vitesse_periode_ms; // pas de nouvelle période -> garder l'ancienne valeur 321
322 | // v = distance / temps = PAS_M / (periode_us / 1 000 000)
323 | float v_brute = PAS_M / ((float)periode_us / 1000000.0f);
324
325 | // Rejet des parasites : si le saut de vitesse est physiquement impossible -> ignorer
326 | if (vitesse_periode_ms > 0.0f
327 | && fabsf(v_brute - vitesse_periode_ms) > DELTA_V_MAX) {
328 | return vitesse_periode_ms; // mesure rejetée, on conserve la valeur précédente
329 | }
330
331 | // Filtre exponentiel asymétrique :
332 | // | montée -> alpha = 0.25 (filtre fort : atténue les fausses vitesses élevées)
333 | // | descente -> alpha = 0.85 (filtre faible : suit vite la décélération réelle)
334 | // v_filtré = alpha * v_brute / (1-alpha) * v_filtré_précédent
335 | float alpha = (v_brute >= vitesse_periode_ms) ? 0.25f : 0.85f;
336
337 | if (vitesse_periode_ms == 0.0f) { // premier calcul : initialiser directement sans filtrage
338 | vitesse_periode_ms = v_brute;
339 | } else {
340 | vitesse_periode_ms = alpha * v_brute + (1.0f - alpha) * vitesse_periode_ms; // filtre
341 | }
342
343 return vitesse_periode_ms; // retourner la vitesse filtrée en m/s
344 }
345
346
347 // envoi PWM au moteur
348 void appliquerCommande(float cmd) {
349 | // Zone morte : entre 0 et 76 PWM le moteur ne produit aucun couple.
350 | // On force à 0 pour éviter que l'intégrale accumule une erreur fictive.
351 | if (cmd > 0.0f && cmd < PWM_ZONE_MORTE) cmd = 0.0f;
352
353 int pwm = (int)constrain(cmd, -255.0f, 255.0f); // limiter entre -255 et +255 et convertir en entier 354
355 | if (pwm >= 0) { // commande positive -> sens avant
356 | digitalWrite(IN3_PIN, HIGH); // IN3 = HIGH : sélectionne le sens avant
357 | digitalWrite(IN4_PIN, LOW); // IN4 = LOW : complément de IN3
358 | analogWrite(ENB_PIN, (uint8_t)pwm); // ENB : fixer la puissance par PWM (0…255)
359 | } else { // commande négative -> freinage actif / sens arrière
360 | digitalWrite(IN3_PIN, LOW); // IN3 = LOW : sens inverse
361 | digitalWrite(IN4_PIN, HIGH); // IN4 = HIGH : complément de IN3
362 | analogWrite(ENB_PIN, (uint8_t)(-pwm)); // valeur absolue pour PWM (toujours positif 0…255)
363 | }
364 }
365
366
367 // calcule la commande à partir de l'erreur en la faisant apsser dans le correcteur 368 float calculerCorrecteur(float erreur, float dt_s, bool reinitDerivee) {
369
370 | // terme P
371 | float u_P = Kp_VAL * erreur; // proportionnel : réponse immédiate proportionnelle à l'écart courant
372
373 | // terme I
374 | float u_I = 0.0f; // initialiser à 0 ; sera calculé seulement si USE_I = 1
375 #if USE_I // bloc compilé seulement si le correcteur a une intégrale (PI ou PID)
376 | if (!kickActif) { // NE PAS intégrer pendant le kick (anti-windup kick)
377 | integrale += erreur * dt_s; // intégrale discrète : I += eps × delta_t (approximation rectangulaire)
378 | integrale = constrain(integrale, // saturation anti-windup : limiter l'intégrale à + ou - INTEGRALE_MAX
379 | -INTEGRALE_MAX,
380 | INTEGRALE_MAX);
381 | }
382 | u_I = Ki_VAL * integrale; // terme intégral en PWM = Ki * intégrale(eps*dt)
383 #endif
384
385 | // terme D (sur le mesure pas sur l'erreur)
386 | float u_D = 0.0f; // initialiser à 0 ; sera calculé seulement si USE_D = 1
387 #if USE_D // bloc compilé seulement si le correcteur a une dérivée (PD ou PID)
388 | if (!reinitDerivee && deriveeInitialisee && dt_s > 0.0f) {
389 | // dv/dt ~= (v_actuel − v_précédent) / delta_t | (dérivée numérique 1er ordre)
390 | float dv_dt = (vitesse_periode_ms - vitessePeriodePrecedente) / dt_s;
391 | // u_D = −Kd * dv/dt car d(erreur)/dt = −dv/dt (Vc constant en régime)
392 | u_D = -Kd_VAL * dv_dt;
393 | }
394 | // reinitDerivee = vrai lors d'une transition de mode -> on saute ce cycle
395 | // deriveeInitialisee = faux au démarrage ou après un kick -> pas de "précédent" disponible
396 #endif
397
398 | vitessePeriodePrecedente = vitesse_periode_ms; // mémoriser la vitesse pour le prochain calcul D
399 | deriveeInitialisee = true; // indiquer que le "précédent" est maintenant valide
400
401 return u_P + u_I + u_D; // retourner la somme des trois termes PID (en PWM)
402 }
403
404
405 /* calcule la commande du moteur à partir de la commande du correcteur
406 et applique la logique du kick-start et la rampe asymétrique */
407 float calculerCommandeMoteur(float cmdCorrecteur, float dt_s, bool urgence, bool interdireKick, uint32_t now) { 408
409 | static uint32_t kickFinMs = 0; // timestamp de la fin du dernier kick
410 | const uint16_t KICK_GRACE = 300; // délai de grâce après un kick : 300 ms sans nouveau kick
411
412 | // mode urgence, bypass tout
413 | if (urgence) {
414 | kickActif = false; // couper tout kick en cours
415 | commandeLisseePWM = cmdCorrecteur; // mettre la rampe à jour

return cmdCorrecteur; // retourner la commande d'urgence sans rampe ni kick
}

if (interdireKick) kickActif = false; // si obstacle proche -> couper le kick immédiatement

// Kick en cours : continuer tant que conditions satisfaîtes
if (kickActif) {
if ((now - kickDebutMs) < KICK_DUREE_MS_C // kick encore dans sa durée maximale ?
&& vitesse_periode_ms < VITESSE_QUASI_NULLE_MS) { // ET roue encore quasi arrêtée ? commandeLisseePWM = KICK_PWM_C; // maintenir la rampe au niveau du kick
return (float)KICK_PWM_C; // envoyer la commande kick directement (sans rampe)
} else { // fin du kick (durée écoulée OU voiture a démarré)
kickActif = false; // désactiver le drapeau kick
kickFinMs = now; // mémoriser l'heure de fin pour le délai de grâce
deriveeInitialisee = false; // réinitialiser D : évite le pic delta_v au premier cycle post-kick integrale = 0.0f; // réinitialiser I : évite le windup accumulé pendant le kick commandeLisseePWM = FEEDFORWARD_PWM; // repartir la rampe depuis le feedforward (transition douce) }
}

// déclenchement d'un nouveau kick
bool graceActive = (now - kickFinMs) < KICK_GRACE; // vrai si on est dans les 300 ms post-kick bool roueArretee = (vitesse_periode_ms < VITESSE_QUASI_NULLE_MS) // mesure période < 0.05 m/s
439 | && (vitesse_ms | < VITESSE_QUASI_NULLE_MS); // ET mesure fréq < 0.05 m/s

if (!interdireKick // kick non interdit (pas d'obstacle proche) ?
&& !graceActive // délai de grâce écoulé (évite les kicks en rafale) ?
&& cmdCorrecteur > COMMANDE_MIN_DEMARRAGE // le correcteur demande bien d'avancer ?
&& roueArretee) { // les deux mesures confirment que la roue est arrêtée ? integrale = 0.0f; // reset I au lancement kick (anti-windup)
deriveeInitialisee = false; // reset D (v=0 -> pas de "précédent" fiable)
| kickActif = true; // activer le kick
kickDebutMs = now; // mémoriser l'heure de début
commandeLisseePWM = KICK_PWM_C; // initialiser la rampe au niveau kick return (float)KICK_PWM_C; // retourner la commande kick immédiatement
}
| // rampe asymétrique
float cible = constrain(cmdCorrecteur, 0.0f, 255.0f); // limiter la cible à [0, 255] PWM

// calcul du déplacement maximal autorisé ce cycle selon la direction
float dMax = (cible < commandeLisseePWM) // si on descend (frein ou décélération)
? RAMPE_DESCENTE_PAR_S * dt_s // descente rapide : 700 PWM/s * delta_t : RAMPE_MONTEE_PAR_S * dt_s; // montée lente : 350 PWM/s * delta_t

float delta = constrain(cible - commandeLisseePWM, -dMax, dMax); // delta limité à + ou - dMax commandeLisseePWM += delta; // avancer la rampe d'un pas vers la cible

return constrain(commandeLisseePWM, 0.0f, 255.0f); // retourner la commande lissée, bornée [0,255] 465 }

468 // initialisation
469 void setup() {
Serial.begin(115200); // démarrer le port série à 115 200 baud pour les messages de debug

Serial.print(F("=== AAC TIPE v19 — correcteur : ")); // afficher la version et le correcteur actif Serial.print(MODE_STR); // afficher "P", "PI", "PD" ou "PID" selon la sélection
| Serial.println(F(" ==="));
| // capteur ultrason HC-SR04
pinMode(TRIG_PIN, OUTPUT); // TRIG est une sortie : on génère l'impulsion pinMode(ECHO_PIN, INPUT); // ECHO est une entrée : on mesure le retour
digitalWrite(TRIG_PIN, LOW); // s'assurer que TRIG est bas au démarrage
| // capteur à effet Hall
pinMode(HALL_PIN, INPUT_PULLUP); // activer la résistance de pull-up interne (signal actif LOW) // Attacher l'ISR hallISR() à l'interruption INT0 (broche 2) sur front descendant (FALLING) attachInterrupt(digitalPinToInterrupt(HALL_PIN), hallISR, FALLING);
| // bouton start/stop
pinMode(BUTTON_PIN, INPUT_PULLUP); // pull-up interne : bouton appuyé = LOW
buttonLastRawState = digitalRead(BUTTON_PIN); // lire l'état initial pour éviter un faux démarrage buttonStableState = buttonLastRawState; // initialiser l'état stable = état initial
| // pont en H L298N
pinMode(ENB_PIN, OUTPUT); // Enable B : sortie PWM pour la vitesse
pinMode(IN3_PIN, OUTPUT); // IN3 : sortie numérique pour le sens
pinMode(IN4_PIN, OUTPUT); // IN4 : sortie numérique pour le sens (complément de IN3) analogWrite(ENB_PIN, 0); // démarrer avec PWM = 0 -> moteur arrêté
| digitalWrite(IN3_PIN, LOW); // IN3 bas
digitalWrite(IN4_PIN, LOW); // IN4 bas -> pas de courant dans le moteur
| // carte SD via SPI
pinMode(SD_CS_PIN, OUTPUT); // CS de la SD en sortie
digitalWrite(SD_CS_PIN, HIGH); // SD désélectionnée au démarrage
pinMode(10, OUTPUT); // pin SPI maître nécessaire même si non utilisé comme CS digitalWrite(10, HIGH); // mettre HIGH pour ne pas interférer avec le bus SPI
| // calcul du feedforward
// Formule : U_FF = (Vc / K_moteur + seuil_démarrage) * 255
// Cette valeur est la commande qui maintient exactement Vc en régime permanent // si le modèle moteur (K, seuil) est correct.
// On la sature à 250 pour garder 5 PWM de marge pour le terme P.
| FEEDFORWARD_PWM = constrain(
(VITESSE_CIBLE_MS / K_MOTEUR + SEUIL_DEMARRAGE) * 255.0f, // calcul brut
0.0f, 250.0f); // saturation à 250 PWM maxi

// Afficher un résumé des paramètres sur le port série pour vérification avant démarrage Serial.print(F("Vc = ")); Serial.print(VITESSE_CIBLE_MS, 2); Serial.println(F(" m/s")); Serial.print(F("U_FF = ")); Serial.print(FEEDFORWARD_PWM, 1); Serial.println(F(" PWM")); Serial.print(F("Kp_BRAKE = ")); Serial.print(KP_BRAKE_PWM, 1); Serial.println(F(" PWM/m")); Serial.print(F("Kp=")); Serial.print(Kp_VAL, 0);
Serial.print(F(" Ki=")); Serial.print(Ki_VAL, 0);

Serial.print(F(" Kd=")); Serial.print(Kd_VAL, 0); Serial.print(F(" KICK=")); Serial.print(KICK_PWM_C); Serial.print(F(" PWM / ")); Serial.print(KICK_DUREE_MS_C);
Serial.println(F(" ms"));

initSD(); // tenter d'ouvrir un nouveau fichier CSV sur la carte SD lastControlTime = millis(); // initialiser le timer de contrôle à l'instant présent lastLogTime = millis(); // initialiser le timer de log à l'instant présent
528 }

530 /* boucle principale
log : toutes les 100 ms
correcteur : toutes les 50 ms */
533 void loop() {
uint32_t now = millis(); // lire l'horloge système en millisecondes (débordement tous les 49 jours)

gererBoutonStartStop(now); // vérifier l'état du bouton et décider start/stop

if (!programmeActif) { // si le programme est à l'arrêt :
appliquerCommande(0.0f); // forcer le moteur à 0 en permanence (sécurité) lastControlTime = now; // maintenir le timer à jour pour éviter un grand dt au démarrage lastLogTime = now; // idem pour le timer de log
return; // sortir immédiatement de loop() sans rien calculer
}

// bloc de contrôle (toutes les 50 ms)
if (now - lastControlTime >= CONTROL_PERIOD_MS) {
uint32_t dt_ms = now - lastControlTime; // temps réel écoulé depuis le dernier cycle (peut différer de 50 ms) lastControlTime = now; // mettre à jour le timestamp de référence
float dt_s = (float)dt_ms / 1000.0f; // convertir en secondes pour les calculs PID

// étape 1 : mesures
vitesse_ms = calculerVitesse(dt_ms); // vitesse fréquencemétrique (pour log seulement) vitesse_periode_ms = calculerVitessePeriode(); // vitesse période filtrée (utilisée par le PID) float dist_m = lireDistance(); // distance ultrason en mètres (-1 si invalide)

// étape 2 : mémoire d'obstacle
// Le HC-SR04 renvoie parfois -1 (timeout) même avec un obstacle présent.
// Sans mémoire, un seul -1 ferait basculer en mode vitesse pour 50 ms,
// remettant l'intégrale à 0, puis retour en mode distance -> instabilité. // Solution : si une mesure invalide arrive dans les 300 ms suivant une
// mesure valide, on réutilise la dernière valeur valide.
static float derniereDist_m = -1.0f; // dernière distance valide mémorisée
static uint32_t dernierDistTime_ms = 0; // timestamp de la dernière mesure valide const uint16_t OBSTACLE_MEMORY_MS = 300; // durée de validité de la mémoire d'obstacle

if (dist_m >= 0.0f) { // si la mesure est valide
derniereDist_m = dist_m; // mettre à jour la mémoire
dernierDistTime_ms = now; // mémoriser l'heure
}

float dist_eff = dist_m; // commencer avec la mesure brute
if (dist_m < 0.0f // mesure invalide ?
&& derniereDist_m >= 0.0f // on avait une valeur mémorisée ?
&& derniereDist_m < DIST_MAX_OBSTACLE_M // cette valeur signalait un obstacle ?
&& (now - dernierDistTime_ms) < OBSTACLE_MEMORY_MS) { // la mémoire n'a pas expiré ? dist_eff = derniereDist_m; // utiliser la valeur mémorisée à la place de -1
}

// étape 3 : détermination du mode
// 3 modes exclusifs, par ordre de priorité décroissante :
// mode 1 — urgence : obstacle très proche -> freinage maximal immédiat
// mode 2 — vitesse : pas d'obstacle -> maintenir Vc
// mode 3 — distance : obstacle en zone ACC -> maintenir vitesse + freiner si trop proche uint8_t modeActuel;

if (dist_eff > 0.0f && dist_eff < DIST_URGENCE_M + 0.5f * vitesse_periode_ms) {
// urgence : obstacle détecté ET sa distance est inférieure à 6 cm + marge cinétique // la marge 0.5*v permet d'anticiper l'urgence si la voiture roule vite
modeActuel = 1;
} else if (dist_eff < 0.0f || dist_eff >= DIST_MAX_OBSTACLE_M) {
// vitesse : pas d'obstacle détecté (dist=-1) OU obstacle trop loin (>1.20 m) modeActuel = 2;
} else {
// distance : obstacle présent dans la zone [0.06 m, 1.20 m] -> ACC actif modeActuel = 3;
}

// étape 4 : interdire kick si obstacle proche
bool interdireKick = (modeActuel == 3) // en mode distance : toujours interdit
|| (dist_eff > 0.0f && dist_eff < DIST_CONSIGNE_M); // obstacle dans la zone de sécurité

// étape 5 : transition entre les modes
static uint8_t ancienMode = 0; // mode du cycle précédent (persistant entre les appels) bool reinitDerivee = false; // drapeau : réinitialiser le terme D ce cycle ?

if (modeActuel != ancienMode) { // si le mode vient de changer
reinitDerivee = true; // toujours réinitialiser la dérivée lors d'une transition
// (évite un saut sur le terme D à cause du changement d'erreur)

// réinitialiser l'intégrale SEULEMENT en cas de transition depuis/vers l'urgence. // garder l'intégrale évite le saut de commande
if (modeActuel == 1 || ancienMode == 1) {
integrale = 0.0f; // reset I lors d'une transition urgence depuis/vers autre mode }
}
ancienMode = modeActuel; // mémoriser le mode pour la comparaison du prochain cycle

// étape 6 : calcul de la commande
float erreur = 0.0f; // erreur de vitesse eps = Vc − v_mesurée (initialisée à 0) float commande = 0.0f; // commande PWM à envoyer (initialisée à 0)

if (modeActuel == 1) {
// mode 1 : urgence integrale = 0.0f; // vider l'intégrale -> pas d'effet résiduel sur le freinage deriveeInitialisee = false; // invalider le terme D (v peut chuter brutalement)
erreur = VITESSE_CIBLE_MS - vitesse_periode_ms; // calculer l'erreur pour le log uniquement commande = -255.0f; // freinage maximal : -255 PWM -> L298N en sens inverse

} else if (modeActuel == 2) {
// mode 2 : vitesse (régulation de croisière)
// erreur de vitesse : positive si on est trop lent, négative si trop rapide erreur = VITESSE_CIBLE_MS - vitesse_periode_ms;
// calculer la correction PID
float corr = calculerCorrecteur(erreur, dt_s, reinitDerivee);
// commande = feedforward + correction PID
commande = FEEDFORWARD_PWM + corr;

} else {
// mode 3 : distance
erreur = VITESSE_CIBLE_MS - vitesse_periode_ms; // même erreur de vitesse que mode 2 float corr = calculerCorrecteur(erreur, dt_s, reinitDerivee); // même PID que mode 2 float cmd_vitesse = FEEDFORWARD_PWM + corr; // commande qu'on aurait en mode vitesse

// terme de freinage : proportionnel à l'excès de proximité par rapport à Dc
float freinage = KP_BRAKE_PWM * max(0.0f, DIST_CONSIGNE_M - dist_eff);

commande = max(0.0f, cmd_vitesse - freinage); // soustraire le freinage, jamais négatif ici

// anti-windup freinage
650 #if USE_I // ce bloc n'est compilé que pour les correcteurs avec intégrale (PI et PID)
if (freinage > 0.0f) {
integrale -= erreur * dt_s; // soustraire ce qu'on vient d'ajouter dans calculerCorrecteur() integrale = constrain(integrale, -INTEGRALE_MAX, INTEGRALE_MAX); // re-saturer par sécurité }
655 #endif
}

// étape 7 : rampe + kick + zone morte
bool urgence = (modeActuel == 1); // drapeau urgence pour calculerCommandeMoteur()

// appliquer le kick-start et la rampe asymétrique sur la commande calculée commande = calculerCommandeMoteur(commande, dt_s, urgence, interdireKick, now);

// saturation finale à [-255, +255]
commande = constrain(commande, -255.0f, 255.0f);

// anti-windup zone morte
if (commande > 0.0f && commande < PWM_ZONE_MORTE) {
integrale -= erreur * dt_s; // annuler l'intégrale accumulée inutilement integrale = constrain(integrale, -INTEGRALE_MAX, INTEGRALE_MAX); // re-saturer }

derniereCommande = commande; // mémoriser pour le log appliquerCommande(commande); // envoyer au pont en H -> moteur

// étape 8 : log csv
if (now - lastLogTime >= LOG_PERIOD_MS) {
lastLogTime = now; // mettre à jour le timer de log

// en mode vitesse, log dist = -1 (pas d'obstacle, distance non pertinente) float dist_log = (modeActuel == 2) ? -1.0f : dist_eff;

// écrire une ligne CSV sur la carte SD
ecrireLog((float)now / 1000.0f, dist_log, erreur, modeActuel);
}

// étape 9 : debug console
// afficher l'état du système sur le moniteur série à chaque cycle de contrôle (50 ms) Serial.print(F("[")); Serial.print(MODE_STR); Serial.print(F("] ")); // [P], [PI], [PD] ou [PID]

Serial.print(F("mode="));
if (modeActuel == 1) Serial.print(F("URGENCE ")); // mode urgence : freinage
else if (modeActuel == 2) Serial.print(F("VITESSE ")); // mode vitesse : croisière
694 | else Serial.print(F("DIST | ")); // mode distance : ACC actif

Serial.print(F("| v=")); Serial.print(vitesse_periode_ms, 3); // vitesse mesurée (méthode période)
Serial.print(F(" | d=")); Serial.print(dist_m, 3); // distance brute du capteur ultrason
Serial.print(F(" | e=")); Serial.print(erreur, 3); // erreur de vitesse eps = Vc − v
Serial.print(F(" | cmd=")); Serial.print(commande, 1); // commande envoyée au moteur (PWM)

if (modeActuel == 3) { // en mode distance : afficher aussi la valeur du freinage
float fr = KP_BRAKE_PWM * max(0.0f, DIST_CONSIGNE_M - dist_eff); // recalculer le freinage pour l'affichage
Serial.print(F(" | brk=")); Serial.print(fr, 1); // valeur du freinage en PWM
| }
Serial.print(F(" | kick=")); Serial.println(kickActif ? F("OUI") : F("non")); // état du kick
}
708 }

711 // initialisation carte SD
712 void initSD() {
if (!SD.begin(SD_CS_PIN)) { // tenter d'initialiser la SD sur la broche CS définie Serial.println(F("SD : échec init")); // afficher l'erreur sur le port série sdOk = false; // marquer la SD comme non disponible
return; // abandonner l'initialisation
}

char fn[13]; uint8_t n = 0; // nom de fichier et numéro incrémental
| do {
snprintf(fn, sizeof(fn), "%s%03d.CSV", MODE_STR, n++); // générer "PID000.CSV", "PID001.CSV", etc. } while (SD.exists(fn) && n < 255); // incrémenter jusqu'à trouver un nom non utilisé

logFile = SD.open(fn, FILE_WRITE); // ouvrir le fichier en écriture (crée le fichier si inexistant) if (!logFile) { // si l'ouverture a échoué
Serial.print(F("SD : impossible d'ouvrir ")); Serial.println(fn); // afficher l'erreur
sdOk = false; // marquer la SD comme non disponible

return;
}

// Écrire le commentaire d'en-tête avec les paramètres de l'essai (ligne commençant par #) logFile.print(F("#correcteur=")); logFile.print(MODE_STR); // nom du correcteur logFile.print(F(",Kp=")); logFile.print(Kp_VAL, 1); // gain proportionnel logFile.print(F(",Ki=")); logFile.print(Ki_VAL, 1); // gain intégral logFile.print(F(",Kd=")); logFile.print(Kd_VAL, 1); // gain dérivé logFile.print(F(",FF=")); logFile.print(FEEDFORWARD_PWM, 1); // feedforward calculé
logFile.print(F(",Vc=")); logFile.println(VITESSE_CIBLE_MS, 2); // vitesse cible

// Écrire la ligne d'en-tête CSV avec le nom des colonnes logFile.println(F("t_s,mode,vitesse_freq_ms,vitesse_periode_ms,consigne_vitesse_ms,distance_m,consigne_dist_m,erreur_m,commande_pwm"));

logFile.flush(); // forcer l'écriture sur la carte SD (évite la perte des en-têtes en cas de coupure)

strncpy(logFilename, fn, sizeof(logFilename)); // copier le nom du fichier dans logFilename
logFilename[sizeof(logFilename)-1] = '\0'; // s'assurer que la chaîne est bien terminée par '\0' logLinesSinceFlush = 0; // remettre le compteur de lignes depuis le dernier flush à zéro
sdOk = true; // marquer la SD comme opérationnelle

Serial.print(F("SD : ")); Serial.println(fn); // confirmer l'ouverture sur la console
750 }

753 // fermeture propre du fichier
754 void fermerLogSD() {
if (sdOk && logFile) { // si la SD est disponible et le fichier ouvert logFile.flush(); // écrire toutes les données en mémoire tampon sur la carte logFile.close(); // fermer proprement le fichier (finalise l'en-tête FAT)
}
sdOk = false; // marquer la SD comme indisponible jusqu'à la prochaine initSD() 760 }

763 // écris une ligne sur le fichier sur la carte SD
764 void ecrireLog(float t_s, float dist_m, float erreur_m, uint8_t mode) {
if (!sdOk) return; // ne rien faire si la SD n'est pas disponible

logFile.print(t_s, 3); logFile.print(','); // temps en secondes (3 décimales)
logFile.print(mode); logFile.print(','); // mode : 1=urgence, 2=vitesse, 3=distance logFile.print(vitesse_ms, 4); logFile.print(','); // vitesse fréquencemétrique (m/s) logFile.print(vitesse_periode_ms,4); logFile.print(','); // vitesse période filtrée (m/s) — utilisée par PID logFile.print(VITESSE_CIBLE_MS, 4); logFile.print(','); // consigne de vitesse (m/s) — constante logFile.print(dist_m, 4); logFile.print(','); // distance obstacle (-1 si mode vitesse) logFile.print(DIST_CONSIGNE_M, 4); logFile.print(','); // consigne de distance (m) — constante logFile.print(erreur_m, 4); logFile.print(','); // erreur de vitesse ε = Vc − v (m/s) logFile.println(derniereCommande, 1); // commande envoyée au moteur (PWM, newline)

// flush groupé : écrire physiquement sur la SD tous les LOG_FLUSH_EVERY_N_LINES cycles
// (flush à chaque ligne serait trop lent et userait la carte SD inutilement)
if (++logLinesSinceFlush >= LOG_FLUSH_EVERY_N_LINES) {
logFile.flush(); // forcer l'écriture du buffer SD sur la carte
logLinesSinceFlush = 0; // remettre le compteur à zéro
}
783 }

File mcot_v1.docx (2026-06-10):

REYNAUD Emile

# Régulateur de vitesse adaptatif et boucle de rétroaction PID

Professeur encadrant : M. BOUTIN

# A) Ancrage au thème de l’année (50 mots max)

Mon TIPE porte sur l’étude de la boucle de rétroaction, ou boucle de correction, d’un régulateur de vitesse adaptatif miniaturisé.

# B) Motivation du choix de l’étude (50 mots max)

J’ai toujours été passionné par l’automobile, et lorsque j’ai découvert le régulateur de vitesse adaptatif en essayant une voiture, ma curiosité l’a emportée et j’ai tout de suite voulu savoir comment ce système fonctionnait et comment l’améliorer.

# C) Mise en cohérence des objectifs du TIPE (MCOT)

## C.1. Positionnement thématique

A choisir dans la liste proposée sur SCEI :

Thème 1 : Automatique

Thème 2 : Électronique

Thème 3 : Génie mécanique

## C.2. 5 mots clés

| Français | Anglais
Mot clé 1 | Régulateur de vitesse adaptatif | Adaptive Cruise Control
Mot clé 2 | Asservissement PID | PID Control
Mot clé 3 | Boucle de rétroaction | Feedback Loop
Mot clé 4 | Miniaturisation | Miniaturization
Mot clé 5 | Optimisation | Optimization

## C.3. Bibliographie commentée (550 à 650 mots)

Le développement des systèmes de régulation de vitesse et d’aide à la conduite s’inscrit dans une évolution plus large vers l’automatisation progressive du véhicule. Les travaux de synthèse consacrés aux Advanced Driver Assistance Systems (ADAS) mettent en évidence la transition entre assistance humaine et autonomie complète, en soulignant les enjeux de sécurité, de robustesse et de fiabilité des systèmes embarqués [1]. Ces systèmes reposent sur des architectures complexes combinant capteurs, algorithmes de perception et lois de commande, dont la cohérence conditionne directement les performances globales du véhicule. Dans ce cadre, le contrôle longitudinal apparaît comme une fonction clé, à la fois pour le confort de conduite et pour la prévention des collisions.

Le régulateur de vitesse adaptatif (Adaptive Cruise Control, ACC) constitue l’une des premières applications concrètes de ces architectures. Il vise à maintenir une vitesse de consigne tout en garantissant une distance de sécurité avec le véhicule précédent. Les approches classiques de commande, notamment les régulateurs PID, restent largement utilisées dans les prototypes et applications industrielles en raison de leur simplicité, de leur robustesse et de leur facilité d’implémentation sur des calculateurs embarqués. Les études portant sur la conception d’un ACC basé sur un PID, en particulier sur des véhicules électriques, montrent qu’un réglage adéquat des gains permet d’obtenir un compromis satisfaisant entre rapidité de réponse, stabilité et limitation du dépassement [2]. Ces travaux mettent cependant en évidence une forte dépendance des performances aux paramètres du système et aux conditions d’utilisation.

Les limites des méthodes de réglage traditionnelles, souvent basées sur des essais empiriques ou des règles heuristiques, apparaissent clairement lorsque le système devient non linéaire ou soumis à des perturbations variables. C’est dans ce contexte que s’inscrivent les recherches visant à automatiser l’optimisation des lois de commande. Les métaheuristiques constituent une famille d’outils particulièrement adaptée à ce type de problématique, car elles permettent d’explorer efficacement de vastes espaces de paramètres sans nécessiter de modèle analytique parfaitement exact. Les travaux de Naranjo, Serradilla et Nashashibi illustrent cette approche en proposant une optimisation du contrôle de vitesse pour véhicules autonomes à l’aide d’algorithmes métaheuristiques [3]. Les résultats obtenus montrent une amélioration simultanée de plusieurs critères, tels que la stabilité dynamique, le confort des passagers et la consommation énergétique.

Dans la continuité de ces recherches, l’utilisation d’algorithmes d’optimisation bio-inspirés pour le réglage de régulateurs PID appliqués au Cruise Control automobile fait l’objet d’un intérêt croissant. L’algorithme Red Panda Optimization, par exemple, s’inscrit dans cette dynamique en proposant une nouvelle stratégie d’exploration de l’espace des solutions [4]. Appliqué à un système de régulation de vitesse, il permet d’obtenir des performances supérieures aux méthodes classiques de réglage, notamment en termes de temps de réponse et de dépassement maximal. L’intérêt majeur de cette approche réside dans le fait qu’elle conserve une structure de commande simple, compatible avec les contraintes industrielles, tout en améliorant significativement les performances.

Enfin, l’ensemble de ces contributions doit être replacé dans une réflexion plus globale sur l’intégration du régulateur de vitesse au sein de systèmes autonomes complets. Les travaux de synthèse sur les ADAS rappellent que la performance d’un régulateur ne peut être évaluée isolément, mais dépend étroitement de la qualité de la perception de l’environnement, de la fiabilité des capteurs et de la coordination avec les autres fonctions du véhicule [1]. Le contrôle longitudinal optimisé apparaît ainsi à la fois comme un champ d’étude autonome mobilisant des outils de modélisation, de commande et d’optimisation, et comme un élément fondamental des architectures de conduite automatisée, ce qui en fait un sujet particulièrement pertinent dans le cadre d’un TIPE de CPGE PT.

## C.4. Problématique retenue (50 mots max)

Comment le fonctionnement d’un régulateur de vitesse adaptatif peut-il être modélisé et analysé à travers sa boucle de correction, et dans quelle mesure les choix de commande influencent-ils sa stabilité et ses performances dynamiques ?

## C.5. Objectifs du TIPE (100 mots max)

L’objectif de ce TIPE est d’étudier le fonctionnement d’un régulateur de vitesse adaptatif en modélisant sa boucle de correction. Il s’agit d’analyser le comportement dynamique du système en réponse à différentes conditions de circulation et de perturbations, puis d’évaluer l’influence des paramètres de commande sur la stabilité, la rapidité et le confort. Cette étude vise également à comparer des méthodes de réglage classiques et optimisées afin d’identifier leurs apports et leurs limites dans le cadre du contrôle longitudinal automobile.

## C.6. Liste de références bibliographiques (2 à 10)

Auteur 1, Auteur 2 | Titre | Référence (ex : année, journal, mémoire de thèse de l’université de… cf. consignes scei et cf. « citer » dans google scholar)
Kukkala et al. | Advanced Driver-Assistance Systems: A Path Toward Autonomous Vehicles | IEEE Consumer Electronics Magazine, 2018
Saputro et al. | Design of an Adaptive Cruise Control System using PID Control Method on Electric Vehicle Prototypes | ICAMIMIA, 2023
Naranjo, Serradilla, Nashashibi | Speed Control Optimization for Autonomous Vehicles with Metaheuristics | Electronics, 2020
Saravanan G. et al. | Red Panda Optimization Algorithm-Based PID Controller Design for Automobile Cruise Control System | ICSSEECC, 2024

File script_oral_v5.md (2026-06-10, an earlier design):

# Script oral — TIPE AAC v4 — 15 minutes
> **19 slides, ~45 s par slide en moyenne. Parlez lentement et clairement.**

---

## Diapo 1 — Titre *(30 s)*

« Bonjour. Mon TIPE porte sur la conception et la comparaison expérimentale de correcteurs PID pour un régulateur de vitesse adaptatif — un ACC miniature sur voiture RC. L'ancrage au thème "Cycles et boucles" est la boucle de régulation elle-même, exécutée en cycle discret toutes les 50 ms. »

---

## Diapo 2 — Ancrage et problématique *(50 s)*

« La boucle de régulation est un cycle classique de l'automatique : on compare la consigne de vitesse à la mesure, l'écart alimente le correcteur qui commande le moteur, et le capteur Hall ferme la boucle. Ce cycle se répète 20 fois par seconde — c'est le cœur de l'ancrage au thème.

La problématique : quel correcteur P, PI, PD ou PID associé à un feedforward offre le meilleur compromis stabilité-précision pour un ACC miniature ? »

---

## Diapo 3 — Maquette *(45 s)*

« La maquette embarque cinq éléments. Un Arduino Nano Every joue le rôle du calculateur embarqué. Un pont en H L298N pilote le moteur brushed RC390. Un HC-SR04 mesure la distance obstacle. Trois aimants et un capteur Hall mesurent la vitesse. Tout est enregistré en CSV sur microSD à 10 Hz pour analyse post-expérience. »

---

## Diapo 4 — Identification du moteur *(55 s)*

« Avant de concevoir le correcteur, j'ai identifié le moteur par un modèle de premier ordre : v = K × (u − seuil). J'ai réalisé 9 échelons PWM de 40 à 240 et mesuré K = 1,4 m/s et τ = 250 ms.

Ce modèle sert à calculer le feedforward : U_FF = (Vc/K + seuil) × 255 = 204 PWM. C'est la commande d'équilibre qui place le moteur directement au bon point de fonctionnement. Sans ça, le PID seul s'annulerait quand l'erreur tend vers zéro — et le moteur s'arrêterait. »

---

## Diapo 5 — Mesure de vitesse fréquencemétrique *(40 s)*

« La méthode fréquencemétrique compte les impulsions Hall sur 50 ms. Elle est précise à haute vitesse mais inutilisable en dessous de quelques impulsions par cycle — son incertitude dépasse 249 % à 0,70 m/s. Je l'utilise uniquement pour le log. »

---

## Diapo 6 — Mesure de vitesse — méthode période *(45 s)*

« La méthode période mesure la durée entre deux aimants consécutifs. Son incertitude est 155 fois plus faible : 2,3 % relatif constant. C'est elle qui alimente le correcteur PID. Un filtre exponentiel asymétrique la protège contre les rebonds mécaniques tout en suivant rapidement les décélérations. »

---

## Diapo 7 — Architecture 2-DOF + mode ACC *(60 s)*

« L'architecture retenue est 2-DOF : le feedforward positionne le moteur au point d'équilibre, et le PID corrige les écarts résiduels. La commande totale est U_FF + Kp × ε + Ki × ∫ε dt + Kd × dε/dt.

En mode distance, j'ai adopté une architecture ACC réaliste. Au lieu de réguler sur l'erreur de distance, la commande reste celle du régulateur de vitesse, et on lui soustrait un terme de freinage uniquement si l'obstacle est trop proche : cmd = cmd_vitesse − 600 × max(0, Dc − d). Si l'obstacle est loin, la voiture maintient sa vitesse sans accélérer vers lui. »

---

## Diapo 8 — Correcteur P — courbe *(40 s)*

« Sur la courbe du correcteur P avec Kp = 60, on voit immédiatement l'erreur statique : la voiture se stabilise à 0,47 m/s au lieu de 0,70 — un écart de 33 %. En mode distance, regardez la commande en bas : les saccades caractéristiques dues au bruit de mesure amplifié par Kp sans lissage. »

---

## Diapo 9 — Correcteur P — analyse *(40 s)*

« L'erreur statique de 33 % est structurelle : le terme P seul calcule Kp × ε, et ne peut atteindre Vc que si ε est non nul en permanence. K_réel ≠ K_nom à cause de la décharge batterie — le feedforward ne compense pas entièrement ce biais. Le P sert de référence pour la suite. »

---

## Diapo 10 — Correcteur PI — courbe *(40 s)*

« Le PI avec Kp = 15 et Ki = 60. On voit la montée progressive vers 0,70 m/s — l'intégrale qui s'accumule sur 8 secondes pour compenser le biais de K. Le système est amorti, aucun dépassement. »

---

## Diapo 11 — Correcteur PI — analyse *(40 s)*

« L'intégrale élimine l'erreur statique — elle converge vers 0 — mais au prix d'un temps de réponse de 7,5 secondes. C'est rédhibitoire en conditions réelles : à 0,70 m/s la voiture parcourt 5 mètres avant d'être à vitesse. Kp = 15 volontairement faible garantit la stabilité malgré le fort Ki. »

---

## Diapo 12 — Correcteur PD — courbe *(40 s)*

« Le PD avec Kp = 350 et Kd = 10. La réponse est rapide — tr5% ≈ 1,5 s — et le dépassement de 14 % est clairement visible à la montée. La dérivée est calculée sur la mesure de vitesse et non sur l'erreur, ce qui évite le pic brutal lors des transitions de mode. »

---

## Diapo 13 — Correcteur PD — analyse *(40 s)*

« Le PD est le plus rapide, mais deux défauts : l'erreur statique de 19 % persiste — sans intégrale, elle est irréductible. Et le dépassement de 14 % dépasse la norme industrielle de 5 %. Bon transitoire, mauvais état final. »

---

## Diapo 14 — Correcteur PID — courbe *(45 s)*

« Le PID avec Kp = 80, Ki = 40 et Kd = 8. On voit les trois comportements combinés : démarrage avec léger dépassement de 4,8 %, puis convergence rapide vers 0,70 m/s en ~4 secondes, erreur résiduelle inférieure à 1 %. En mode distance, la vitesse reste stable jusqu'à ce que l'obstacle soit trop proche — puis le freinage s'active progressivement. »

---

## Diapo 15 — Correcteur PID — analyse *(45 s)*

« Seul le PID satisfait les trois critères simultanément. Erreur statique inférieure à 1 % — l'intégrale compense le biais en ~5 s. Dépassement 4,8 %, en dessous de la norme de 5 %. Temps de réponse de 4 secondes, bon compromis entre le PI trop lent et le PD trop imprécis. L'anti-windup gèle l'intégrale pendant le freinage en mode distance pour éviter l'accélération parasite au retour. »

---

## Diapo 16 — Comparaison *(45 s)*

« Ce tableau résume tout. P : erreur de 33 %, éliminatoire. PI : précis mais 7,5 s de réponse. PD : rapide mais 14 % de dépassement hors norme. PID : erreur < 1 %, dépassement 4,8 % ≤ 5 %, tr5% = 4 s. Et en mode distance, le comportement ACC est correct. La réponse à la problématique est claire. »

---

## Diapo 17 — Limites *(35 s)*

« Quatre limites identifiées. Le HC-SR04 a une résolution de 2 cm. K varie avec la batterie, ce qu'un observateur adaptatif pourrait corriger. Les oscillations résiduelles sont liées à la zone morte du moteur. Et l'inertie réelle de la voiture rend τ_réel légèrement supérieur au modèle. »

---

## Diapo 18 — Conclusion *(35 s)*

« En conclusion : l'architecture 2-DOF avec PID est la solution optimale sur cette maquette. Les critères sont validés expérimentalement. Le mode distance v19 reproduit le comportement d'un vrai ACC. Et l'ancrage est fort : la boucle fermée est littéralement un cycle discret — mesure, calcul, action — répété 20 fois par seconde. »

---

## Diapo 19 — Bibliographie *(20 s)*

« Quatre références couvrant le contexte industriel ADAS et les aspects techniques PID sur Arduino. Je reste disponible pour toute question. »

---

## Chronomètre estimé

| # | Slide | Durée | Cumul |
|---|---|---|---|
| 1 | Titre | 0:30 | 0:30 |
| 2 | Ancrage + Problématique | 0:50 | 1:20 |
| 3 | Maquette | 0:45 | 2:05 |
| 4 | Identification moteur | 0:55 | 3:00 |
| 5 | Méthode fréquencemétrique | 0:40 | 3:40 |
| 6 | Méthode période | 0:45 | 4:25 |
| 7 | Architecture + mode ACC | 1:00 | 5:25 |
| 8 | P — courbe | 0:40 | 6:05 |
| 9 | P — analyse | 0:40 | 6:45 |
| 10 | PI — courbe | 0:40 | 7:25 |
| 11 | PI — analyse | 0:40 | 8:05 |
| 12 | PD — courbe | 0:40 | 8:45 |
| 13 | PD — analyse | 0:40 | 9:25 |
| 14 | PID — courbe | 0:45 | 10:10 |
| 15 | PID — analyse | 0:45 | 10:55 |
| 16 | Comparaison | 0:45 | 11:40 |
| 17 | Limites | 0:35 | 12:15 |
| 18 | Conclusion | 0:35 | 12:50 |
| 19 | Bibliographie | 0:20 | 13:10 |
| **Marge** | | **1:50** | **≤ 15:00** |

> 💡 **Si tu es en avance** : développe davantage les diapos d'analyse (9, 11, 13, 15).  
> **Si tu es en retard** : les diapos 5, 6 (méthodes de mesure) peuvent passer en 25 s chacune — dites juste « fréquencemétrique pour le log, période pour le PID car 155× plus précis ».

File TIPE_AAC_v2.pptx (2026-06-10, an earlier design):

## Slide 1

Régulateur de vitesse adaptatif
et boucle de rétroaction PID

Comment un régulateur de vitesse adaptatif fonctionne-t-il,
et comment sa boucle de correction PID se comporte-t-elle ?

TIPE — Thème : Cycles et boucles | Filière PT

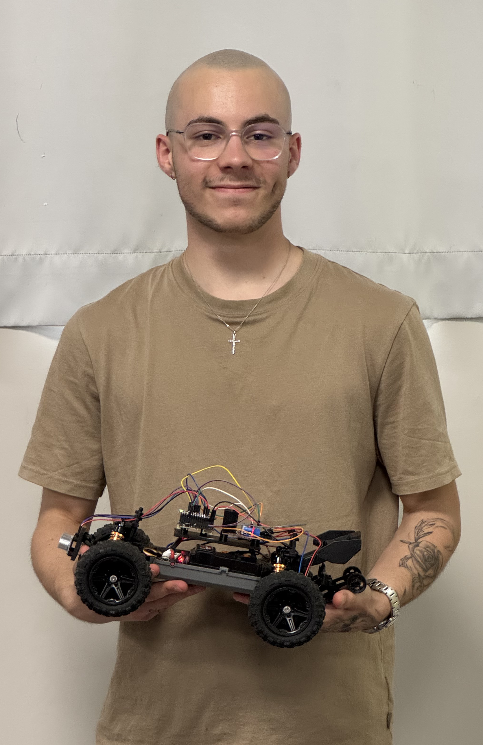
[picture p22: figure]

REYNAUD Emile
N° candidat : 40296

1 / 15

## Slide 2

Ancrage au thème et problématique

Thème : Cycles et boucles

- Boucle de rétroaction : mesure → correcteur → actionneur
- Cycles de correction répétés toutes les 50 ms
- Itérations de réglage P → PI → PD → PID

Problématique

Comment un régulateur de vitesse adaptatif fonctionne-t-il,
et comment sa boucle de correction PID se comporte-t-elle ?

Schéma-bloc de la boucle fermée (notation SI)

Chaîne de retour — y(t) = v(t) mesurée

U_FF = (Vc/K+seuil)×255

U_FF

Vc(t)
0,70 m/s

+
−

ε(t)

C(s)
Correcteur PID

Σ

u(t)

G(s)
Moteur 1er ordre

Voiture

v(t)

m/s

Capteur Hall
(méthode période)

2 / 15

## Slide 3

Maquette expérimentale


Composants

- Arduino Nano Every + shield ASX00061
- Pont en H L298N → moteur brushed RC390
- Capteur ultrason HC-SR04 (distance obstacle)
- Capteur Hall + 3 aimants néodyme (vitesse)
- Carte microSD → log CSV temps réel


3 / 15

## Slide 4

Identification du moteur — Pourquoi et comment ?

Pourquoi identifier le moteur ?

- Le PID seul échoue si on ne connaît pas la commande d'équilibre U_FF : à consigne atteinte, ε→0 donc u_PID→0, le moteur s'arrête (seuil 180/255)
- Identification → modèle du 1er ordre → calcul automatique de U_FF = f(Vc, K, seuil) → régulation possible

Modèle retenu : système du 1er ordre

τ · dv/dt + v(t) = K · u(t)

Réponse à un échelon u = U₀ :

v(t) = K·U₀·(1 − e^(−t/τ))

Lecture graphique de K et τ

K = v∞ / U₀
vitesse de régime ÷ commande normalisée

τ = t tel que v(t) = 63,2 % × v∞
propriété de l'exponentielle : 1−e⁻¹ ≈ 0,632

Protocole expérimental

- 9 échelons successifs : PWM 40 → 240
- Durée : 3 s / échelon (atteindre v∞)
- Mesure v∞ : stabilisation (Δv < 5 mm/s sur 400 ms)
- Mesure τ : 1er passage à 63,2 % de v∞
- Calcul K = v∞ / U₀ avec U₀ = PWM/255

Résultats et conséquences

9,5 m/s

gain statique (batterie chargée)

116,7 ms

constante de temps

0,706 → 180/255

PWM minimal de démarrage

→ U_FF = (0.7/9,5 + 0,706)×255 ≈ 199 PWM (consigne 0.7 m/s)

K

τ

Seuil

4 / 15

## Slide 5

Mesure de vitesse — méthode fréquencemétrique

Principe

- Comptage δ d'impulsions Hall sur T = 50 ms
- 3 aimants → p = πD/N ≈ 0,0873 m
- v = (δ/N) × C / T avec δ ∈ ℕ


Incertitude vs vitesse — méthode fréquencemétrique

Incertitude

- Δδ = ±1 impulsion → Δv = p/T = constante
- Δv = 0,2608/(3×0,050) ≈ 1,74 m/s
- À v = 0,70 m/s : Δv/v ≈ 249 %
- Inutilisable seule pour le terme D

5 / 15

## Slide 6

Mesure de vitesse — méthode période

Principe

- Mesure du temps τ entre 2 fronts Hall consécutifs (ISR)
- Résolution micros() : 4 µs → Δτ = 4 µs
- v = p / τ avec p = 0,0873 m


Δv vs vitesse — méthode période

Incertitude

- Δv ≈ v × Δp/p (terme géométrique dominant)
- Δp/p = 2 mm / 87,3 mm ≈ 2,3 % — relatif constant
- À v = 0,70 m/s : Δv ≈ 0,016 m/s
- ×155 plus précise que la méthode fréquencemétrique

6 / 15

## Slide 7

Architecture du régulateur — Feedforward + PID

Problème du PID pur

- Seuil démarrage : 180/255 — zone morte large
- En régime : ε→0 ⟹ u_PID→0
- Moteur sous le seuil → roue libre → arrêt → re-kick
- Oscillation infinie sans terme constant

Solution : architecture 2-DOF

u(t) = UFF + Kp·ε + Ki·∫ε dt + Kd·(dε/dt)

U_FF = (Vc/K + seuil)×255
= (0.7/9,5 + 0,706)×255 ≈ 199 PWM

FF → maintient la vitesse de régime
PID → corrige les écarts résiduels

Schéma-bloc 2-DOF (Architecture feedforward + correcteur)

Chaîne de retour — mesure v(t)

U_FF = 199 PWM

Vc
0.7 m/s

+
−

ε

C(s)
Correcteur PID

Σ

u

G(s)
K/(τp+1)

Voiture
H=1

v(t)

Capteur Hall
(méthode période)

7 / 15

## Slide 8

Correcteur P (Kp=35) — résultats expérimentaux (Vc = 0.7 m/s)

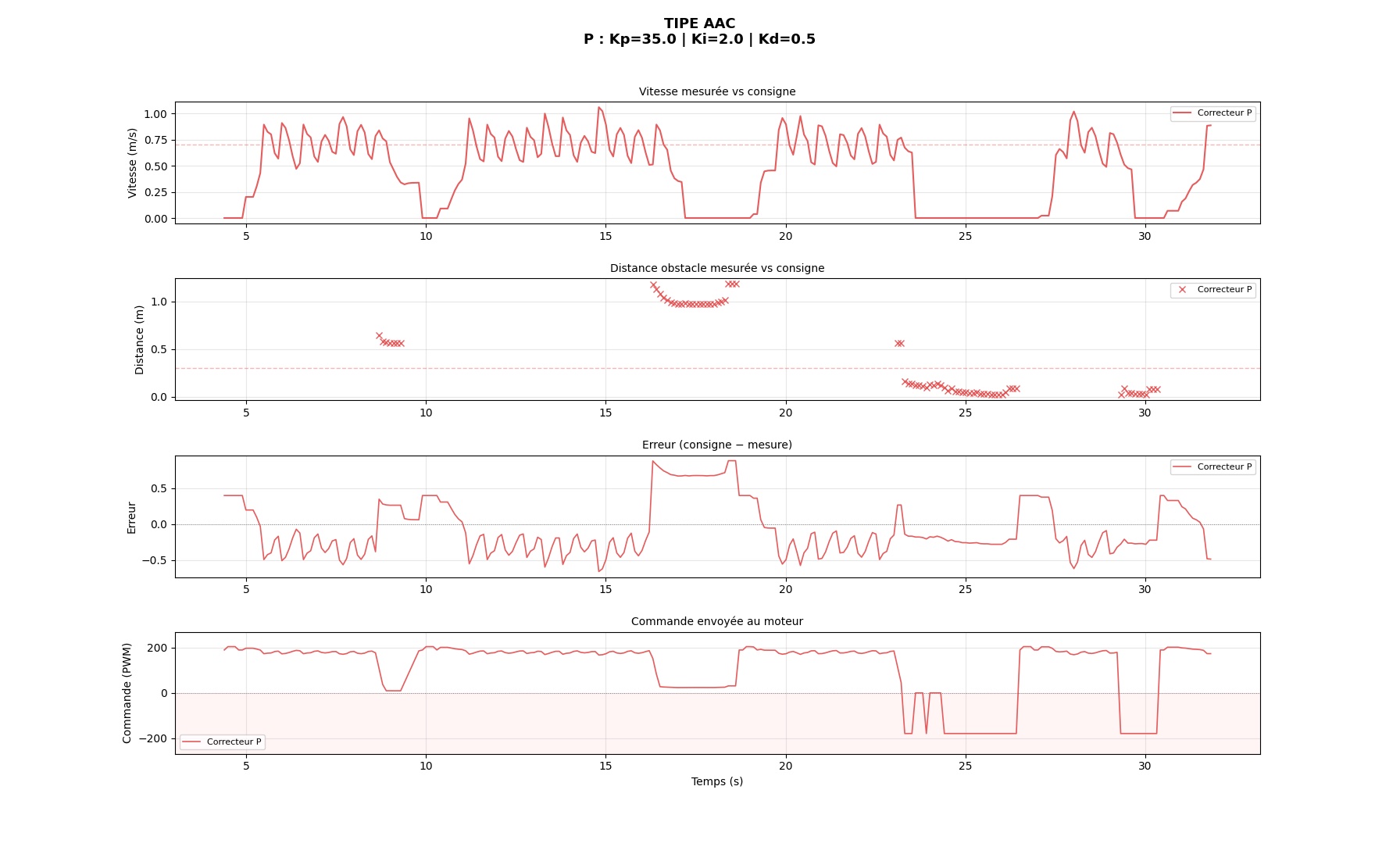
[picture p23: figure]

Mesures expérimentales — vitesse / distance / erreur / commande

Observations positives

- Démarrage rapide — kick-start efficace
- Commande stable ~195 PWM en régime
- Freinage d'urgence bien déclenché

Limites observées

- Erreur statique résiduelle : vitesse oscille ±0,3 m/s autour de 0,7 m/s
- Oscillations entretenues — absence du terme intégral
- Pas de correction des perturbations lentes (décharge batterie)

Bilan

L'erreur statique est structurelle : sans intégrale, le correcteur P ne peut compenser que si ε ≠ 0 en permanence. Point de référence pour PI et PD.

8 / 15
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

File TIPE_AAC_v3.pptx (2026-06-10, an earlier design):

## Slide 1

Régulateur de vitesse adaptatif
et boucle de rétroaction PID

Quel correcteur (P, PI, PD, PID) associé à une architecture feedforward
offre le meilleur compromis stabilité / précision pour un régulateur de vitesse adaptatif ?

📷 Photo
maquette

TIPE — Thème : Cycles et boucles | Filière PT

N° candidat : ________

1 / 19
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

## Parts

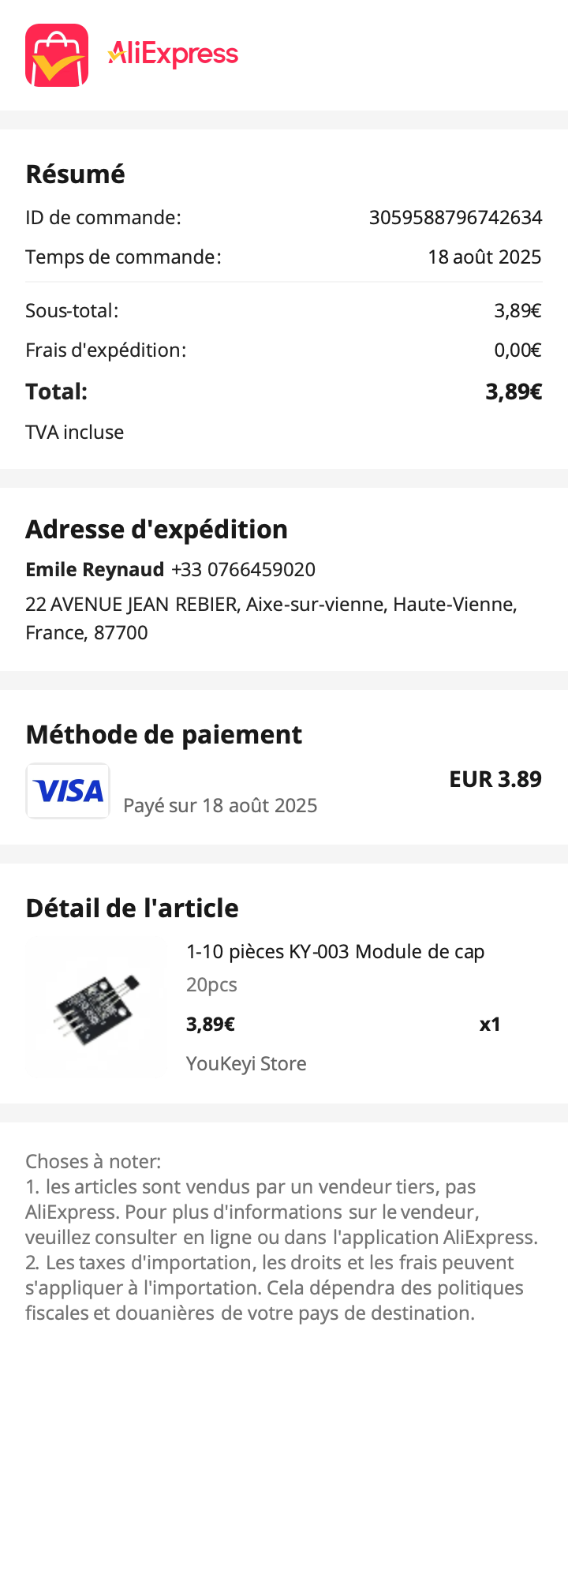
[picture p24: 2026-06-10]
Factures/OrderSummary202508183059588796742634.png

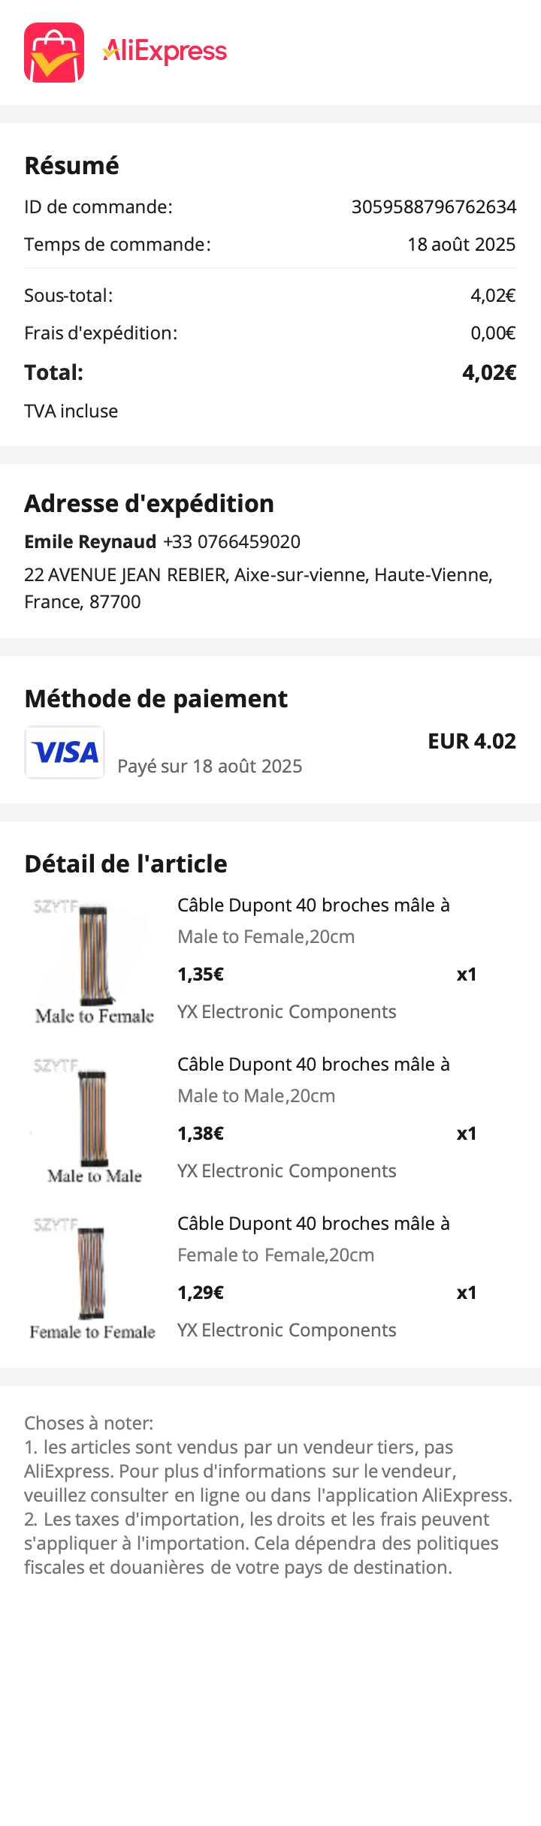
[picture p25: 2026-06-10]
Factures/OrderSummary202508183059588796762634.png

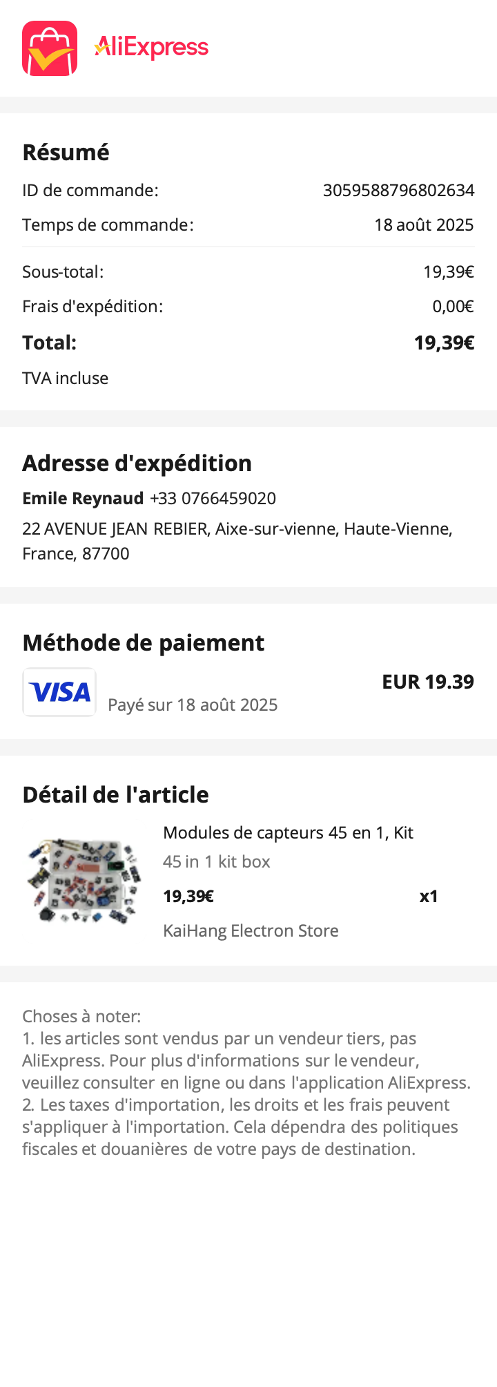
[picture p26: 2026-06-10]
Factures/OrderSummary202508183059588796802634.png

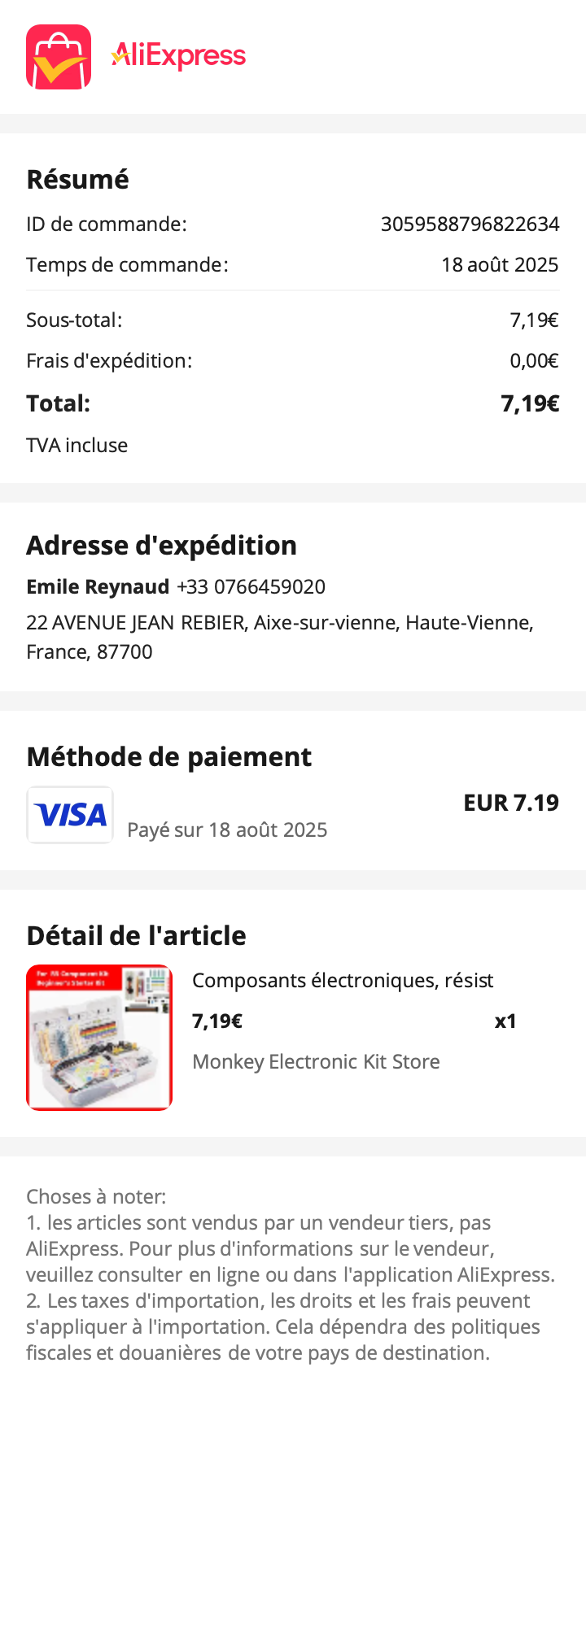
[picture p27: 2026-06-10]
Factures/OrderSummary202508183059588796822634.png

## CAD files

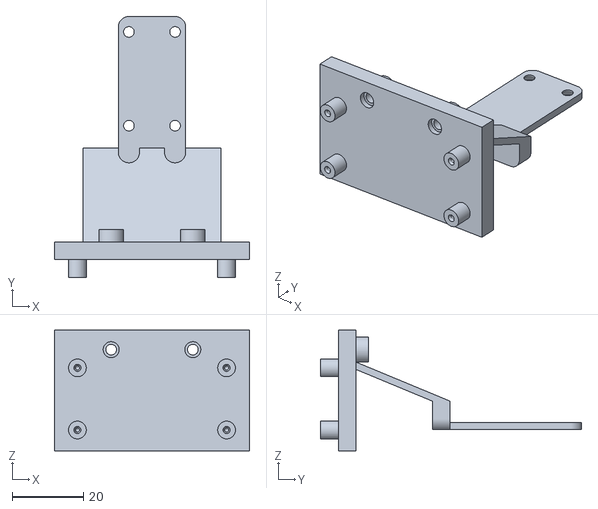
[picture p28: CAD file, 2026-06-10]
Pratique/CAD/support-ultrasound-sensor.stl
55.0 x 73.5 x 34.0

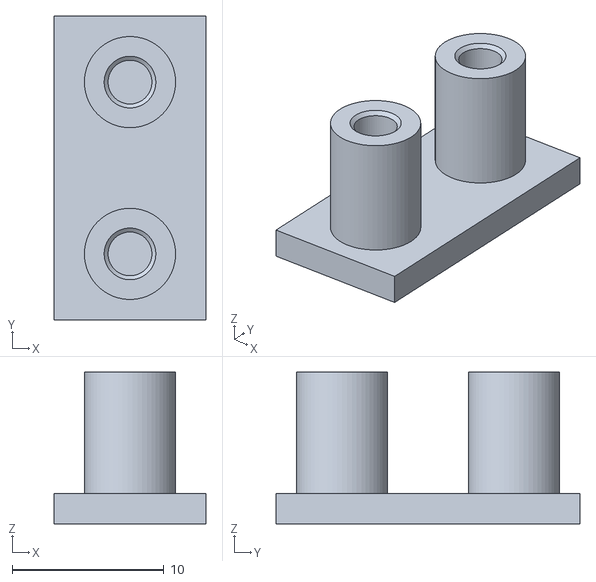
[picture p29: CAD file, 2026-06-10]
Pratique/CAD/test-support-button.stl
10.0 x 20.0 x 10.0

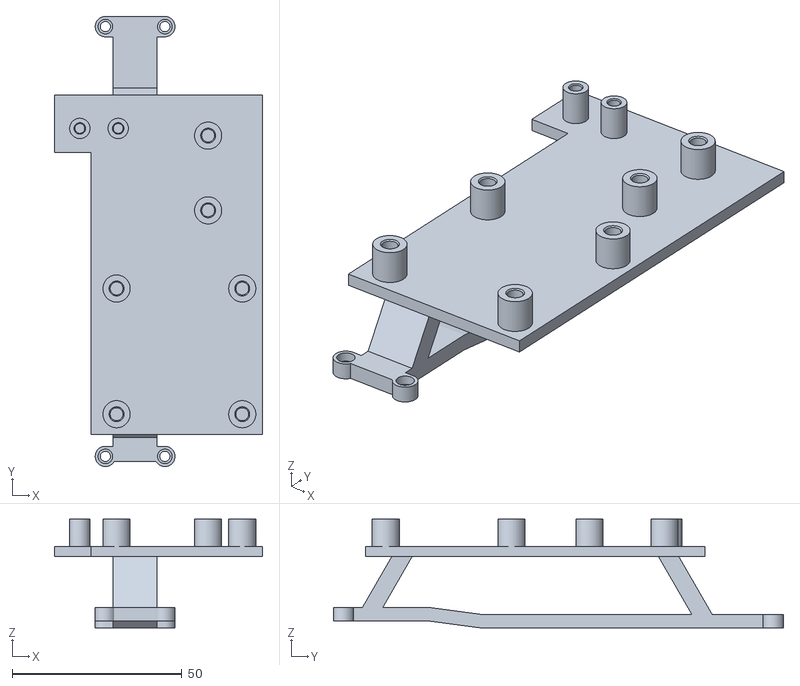
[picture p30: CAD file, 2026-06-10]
Pratique/CAD/support-arduino-rc-car.stl
61.2 x 132.5 x 32.0

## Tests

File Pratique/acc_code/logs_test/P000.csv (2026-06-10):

#correcteur=P | Kp=50.0 | Ki=8.0 | Kd=5.0
t_s | vitesse_freq_ms | vitesse_periode_ms | consigne_vitesse_ms | distance_m | consigne_dist_m | erreur_m | commande_pwm
0 | 0.0 | 0.0 | 0.4 | -1 | 0.3 | 0 | 255
1 | 0.1 | 0.1 | 0.4 | 2 | 0.3 | 1.7 | 200
2 | 0.2 | 0.2 | 0.4 | 1.8 | 0.3 | 1.5 | 180
3 | 0.3 | 0.3 | 0.4 | 1.5 | 0.3 | 1.2 | 100
4 | 0.4 | 0.4 | 0.4 | 1.3 | 0.3 | 0.9 | 50
5 | 0.4 | 0.5 | 0.4 | 0.8 | 0.3 | 0.4 | 50
6 | 0.3 | 0.3 | 0.4 | 0.2 | 0.3 | -0.05 | 0
7 | 0.2 | 0.2 | 0.4 | 0.3 | 0.3 | -0.1 | -10
8 | 0.4 | 0.4 | 0.4 | 0.4 | 0.3 | 0.1 | 120
9 | 0.4 | 0.4 | 0.4 | 0.8 | 0.3 | 0.5 | 50
10 | 0.4 | 0.4 | 0.4 | 1 | 0.3 | 0.7 | 50

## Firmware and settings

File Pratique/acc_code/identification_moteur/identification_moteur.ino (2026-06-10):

/*
 * ============================================================
 *  IDENTIFICATION MOTEUR — estimation de K et τ
 *  TIPE CPGE PT — Arduino Nano Every
 * ============================================================
 *
 *  Principe :
 *  On applique un échelon de PWM au moteur et on mesure la
 *  réponse en vitesse. Le modèle du 1er ordre est :
 *
 *       τ × dv/dt + v(t) = K × u
 *
 *  Réponse à un échelon u = U₀ (constante) en partant de v=0 :
 *
 *       v(t) = K × U₀ × (1 − e^(−t/τ))
 *
 *  On en déduit :
 *    K × U₀ = v_∞         (vitesse de régime permanent)
 *    τ       = temps pour atteindre 63,2 % de v_∞
 *    K       = v_∞ / U₀   (U₀ = PWM_ECHELON / 255, normalisé)
 *
 *  Le programme effectue PLUSIEURS échelons à des PWM différents
 *  (PWM_MIN à PWM_MAX par pas de PWM_PAS) pour :
 *    1) détecter le seuil de démarrage réel du moteur
 *    2) vérifier la linéarité du modèle (K constant sur la plage)
 *    3) estimer τ de façon robuste (moyenne sur plusieurs échelons)
 *
 *  Chaque échelon dure DUREE_ECHELON_MS pour atteindre le régime.
 *  Entre deux échelons, on laisse le moteur s'arrêter (DUREE_ARRET_MS).
 *
 *  Sortie : port série à 115200 bauds.
 *  Format CSV (pour tracer avec Python / Excel) :
 *    t_ms, pwm, vitesse_ms
 *  Puis, après tous les échelons, un résumé :
 *    # PWM_echelon, v_inf_ms, K_estime, tau_estime_ms
 *
 *  Brancher la voiture sur un support (roues en l'air) ou
 *  sur un couloir droit suffisamment long.
 * ============================================================
 */

/* ─── Broches (identiques au projet AAC) ────────────────── */
#define HALL_PIN   2    // Capteur Hall — interruption INT0
#define ENB_PIN    9    // L298N ENB — PWM
#define IN3_PIN    A0   // L298N IN3
#define IN4_PIN    5    // L298N IN4
#define BUTTON_PIN 8    // Bouton START (même câblage que l'AAC)

/* ─── Paramètres physiques (identiques au projet AAC) ────── */
const float   PERIMETRE_M  = 3.14159f * 0.083f;  // π × 83 mm
const uint8_t NB_AIMANTS   = 3;
const float   PAS_M        = PERIMETRE_M / NB_AIMANTS;  // ≈ 0,0869 m

/* ─── Paramètres de l'identification ─────────────────────── */
// Série d'échelons : on teste ces valeurs de PWM une par une.
// On commence bas pour trouver le seuil, on monte pour la linéarité.
const uint8_t ECHELONS[] = {40, 60, 80, 100, 120, 150, 180, 210, 240};
const uint8_t NB_ECHELONS = sizeof(ECHELONS) / sizeof(ECHELONS[0]);

// Durée de chaque phase
const uint32_t DUREE_ECHELON_MS = 3000;  // 3 s : largement suffisant pour le régime
const uint32_t DUREE_ARRET_MS   = 2000;  // 2 s d'arrêt entre deux échelons

// Période d'échantillonnage de la mesure de vitesse
const uint16_t PERIODE_MESURE_MS = 50;   // 50 ms = même que l'AAC

// Seuil pour considérer que le régime permanent est atteint :
// la vitesse ne varie plus de plus de SEUIL_REGIME m/s sur les
// FENETRE_REGIME dernières mesures.
const float   SEUIL_REGIME_MS  = 0.005f; // 5 mm/s de variation max
const uint8_t FENETRE_REGIME   = 8;       // sur 8 × 50 ms = 400 ms

/* ─── Variables Hall (ISR) ────────────────────────────────── */
volatile uint32_t hallCount       = 0;
volatile uint32_t hallLastTime_us = 0;
volatile uint32_t hallPeriode_us  = 0;
volatile bool     hallNouveau     = false;

void hallISR() {
  hallCount++;
  uint32_t now = micros();
  if (hallLastTime_us != 0) {
    hallPeriode_us = now - hallLastTime_us;
    hallNouveau    = true;
  }
  hallLastTime_us = now;
}

/* ─── Variables globales ──────────────────────────────────── */
uint32_t lastHallCount  = 0;
float    vitesse_ms     = 0.0f;  // méthode fréquencemétrique (robuste à basse v)
float    vitesse_per_ms = 0.0f;  // méthode période (précise à v > 0)

// Résultats par échelon
float v_inf[NB_ECHELONS];    // vitesse de régime permanent (m/s)
float tau_ms[NB_ECHELONS];   // constante de temps estimée (ms)
float K_est[NB_ECHELONS];    // gain statique estimé


/* ─── Commande moteur ─────────────────────────────────────── */
void motorAvant(uint8_t pwm) {
  digitalWrite(IN3_PIN, HIGH);
  digitalWrite(IN4_PIN, LOW);
  analogWrite(ENB_PIN, pwm);
}

void motorStop() {
  // Freinage actif pour arrêt rapide entre les échelons
  digitalWrite(IN3_PIN, LOW);
  digitalWrite(IN4_PIN, HIGH);
  analogWrite(ENB_PIN, 200);
  delay(300);
  // Puis roue libre
  analogWrite(ENB_PIN, 0);
  digitalWrite(IN3_PIN, LOW);
  digitalWrite(IN4_PIN, LOW);
}


/* ─── Calcul de vitesse ───────────────────────────────────── */

// Méthode fréquencemétrique : fiable même à très basse vitesse
float calculerVitesseFreq(uint32_t dt_ms) {
  noInterrupts();
  uint32_t count = hallCount;
  interrupts();
  uint32_t delta = count - lastHallCount;
  lastHallCount  = count;
  if (dt_ms == 0) return 0.0f;
  return ((float)delta / NB_AIMANTS) * PERIMETRE_M / (dt_ms / 1000.0f);
}

// Méthode période : précise à vitesse stable
float calculerVitessePeriode() {
  noInterrupts();
  uint32_t dernier = hallLastTime_us;
  interrupts();
  if (dernier == 0) return 0.0f;
  // Timeout 2 s → roue à l'arrêt
  if ((micros() - dernier) > 2000000UL) return 0.0f;
  noInterrupts();
  uint32_t per = hallPeriode_us;
  hallNouveau  = false;
  interrupts();
  if (per == 0) return 0.0f;
  float v = PAS_M / (per / 1000000.0f);
  return (v > 5.0f) ? vitesse_per_ms : v;  // garde-fou rebond
}


/* ─── Attendre le bouton START ────────────────────────────── */
void attendreBouton() {
  Serial.println(F("# Appuyez sur le bouton pour lancer l'identification..."));
  // Attendre relâchement d'abord (sécurité)
  while (digitalRead(BUTTON_PIN) == LOW) delay(10);
  // Attendre appui
  while (digitalRead(BUTTON_PIN) == HIGH) delay(10);
  delay(50);  // anti-rebond
  Serial.println(F("# Démarrage !"));
}


/* ─── Un échelon complet ──────────────────────────────────── */
/*
 * Applique un échelon de PWM `pwm_val` pendant DUREE_ECHELON_MS.
 * Envoie les données CSV sur le port série.
 * Estime v_∞ et τ.
 * Stocke les résultats dans v_inf[idx], tau_ms[idx], K_est[idx].
 */
void faireEchelon(uint8_t idx, uint8_t pwm_val) {

  Serial.print(F("# --- Echelon PWM = "));
  Serial.print(pwm_val);
  Serial.println(F(" ---"));
  Serial.println(F("t_ms,pwm,vitesse_freq_ms,vitesse_per_ms"));

  // Remise à zéro du capteur Hall
  noInterrupts();
  hallCount       = 0;
  hallLastTime_us = 0;
  hallPeriode_us  = 0;
  hallNouveau     = false;
  interrupts();
  lastHallCount = 0;
  vitesse_ms    = 0.0f;
  vitesse_per_ms = 0.0f;

  // Buffer circulaire pour détecter le régime permanent
  float buf_regime[FENETRE_REGIME] = {0};
  uint8_t buf_idx = 0;

  uint32_t t_debut      = millis();
  uint32_t lastMesure   = t_debut;
  float    t63_ms       = -1.0f;  // temps pour atteindre 63,2 % de v_∞
  float    v_max        = 0.0f;   // vitesse max observée (≈ v_∞)
  bool     regime_atteint = false;

  // Appliquer l'échelon
  motorAvant(pwm_val);

  while (millis() - t_debut < DUREE_ECHELON_MS) {
    uint32_t now = millis();

    if (now - lastMesure >= PERIODE_MESURE_MS) {
      uint32_t dt_ms = now - lastMesure;
      lastMesure = now;
      uint32_t t_relatif = now - t_debut;

      // Mesures de vitesse
      vitesse_ms     = calculerVitesseFreq(dt_ms);
      vitesse_per_ms = calculerVitessePeriode();

      // On utilise la méthode période si disponible (plus précise en régime)
      // sinon la méthode fréquencemétrique.
      float v_courante = (vitesse_per_ms > 0.01f) ? vitesse_per_ms : vitesse_ms;

      // Mise à jour de v_max
      if (v_courante > v_max) v_max = v_courante;

      // Détection de τ : premier passage à 63,2 % de v_max actuel
      // On ne le fait qu'une fois (t63_ms == -1) et seulement si
      // v_max est déjà crédible (> 0,02 m/s, pas du bruit).
      // Note : v_max évolue → on utilise une estimation conservative.
      if (t63_ms < 0 && v_max > 0.02f && v_courante >= 0.632f * v_max) {
        t63_ms = (float)t_relatif;
      }

      // Remplissage du buffer de régime
      buf_regime[buf_idx % FENETRE_REGIME] = v_courante;
      buf_idx++;

      // Détection du régime permanent (après au moins une fenêtre complète)
      if (buf_idx >= FENETRE_REGIME && !regime_atteint) {
        float v_min_buf = buf_regime[0], v_max_buf = buf_regime[0];
        for (uint8_t i = 1; i < FENETRE_REGIME; i++) {
          if (buf_regime[i] < v_min_buf) v_min_buf = buf_regime[i];
          if (buf_regime[i] > v_max_buf) v_max_buf = buf_regime[i];
        }
        if ((v_max_buf - v_min_buf) < SEUIL_REGIME_MS) {
          regime_atteint = true;
          // v_∞ = moyenne du buffer
          float somme = 0;
          for (uint8_t i = 0; i < FENETRE_REGIME; i++) somme += buf_regime[i];
          v_inf[idx] = somme / FENETRE_REGIME;
        }
      }

      // Sortie CSV
      Serial.print(t_relatif);        Serial.print(',');
      Serial.print(pwm_val);          Serial.print(',');
      Serial.print(vitesse_ms,   4);  Serial.print(',');
      Serial.println(vitesse_per_ms, 4);
    }
  }

  motorStop();

  // Si le régime n'a pas été détecté automatiquement (PWM trop faible
  // pour démarrer, ou moteur trop lent), v_∞ = v_max observée.
  if (!regime_atteint || v_inf[idx] < 0.005f) {
    v_inf[idx] = v_max;
  }

  // Estimation finale de τ :
  // Si on a détecté le passage à 63,2 % : on utilise t63_ms.
  // Sinon (régime pas atteint à temps) : τ est indéterminé.
  if (t63_ms > 0) {
    tau_ms[idx] = t63_ms;
  } else {
    tau_ms[idx] = -1.0f;  // indéterminé
  }

  // K = v_∞ / U₀   avec U₀ = pwm_val / 255 (normalisé entre 0 et 1)
  float U0 = (float)pwm_val / 255.0f;
  K_est[idx] = (U0 > 0.001f && v_inf[idx] > 0.005f) ? (v_inf[idx] / U0) : 0.0f;

  // Résumé de l'échelon
  Serial.print(F("# Resultat : v_inf="));  Serial.print(v_inf[idx], 4);
  Serial.print(F(" m/s  tau="));
  if (tau_ms[idx] > 0) { Serial.print(tau_ms[idx], 1); Serial.print(F(" ms")); }
  else                  { Serial.print(F("indetermine")); }
  Serial.print(F("  K="));               Serial.println(K_est[idx], 4);
  Serial.println();

  // Pause entre échelons
  delay(DUREE_ARRET_MS);
}


/* ─── Résumé final et conseils ────────────────────────────── */
void afficherResume() {
  Serial.println(F("# ============================================"));
  Serial.println(F("# RESUME DE L'IDENTIFICATION"));
  Serial.println(F("# PWM, v_inf_ms, K_estime, tau_ms"));

  // Calcul des moyennes sur les échelons valides (moteur démarre + τ connu)
  float somme_K   = 0, somme_tau = 0;
  uint8_t n_K = 0, n_tau = 0;
  uint8_t pwm_seuil = 0;  // plus petit PWM avec v_inf > 0,02 m/s

  for (uint8_t i = 0; i < NB_ECHELONS; i++) {
    Serial.print(F("# "));
    Serial.print(ECHELONS[i]);    Serial.print(F(", "));
    Serial.print(v_inf[i], 4);   Serial.print(F(", "));
    Serial.print(K_est[i], 4);   Serial.print(F(", "));
    if (tau_ms[i] > 0) Serial.println(tau_ms[i], 1);
    else                Serial.println(F("N/A"));

    if (K_est[i] > 0.01f) {
      somme_K += K_est[i];
      n_K++;
      if (pwm_seuil == 0) pwm_seuil = ECHELONS[i];
    }
    if (tau_ms[i] > 0) {
      somme_tau += tau_ms[i];
      n_tau++;
    }
  }

  Serial.println(F("# ============================================"));
  Serial.println(F("# VALEURS A ENTRER DANS simulation_AAC.py :"));

  if (n_K > 0) {
    float K_moy = somme_K / n_K;
    Serial.print(F("# K_MOTEUR  = "));
    Serial.println(K_moy, 4);
  } else {
    Serial.println(F("# K_MOTEUR  = indetermine (moteur n'a pas demarre)"));
  }

  if (n_tau > 0) {
    float tau_moy_s = (somme_tau / n_tau) / 1000.0f;
    Serial.print(F("# TAU_MOTEUR = "));
    Serial.print(tau_moy_s, 4);
    Serial.println(F(" s"));
  } else {
    Serial.println(F("# TAU_MOTEUR = indetermine"));
  }

  if (pwm_seuil > 0) {
    float seuil_norm = (float)pwm_seuil / 255.0f;
    Serial.print(F("# SEUIL_DEMARRAGE = "));
    Serial.print(seuil_norm, 3);
    Serial.print(F("  (PWM = "));
    Serial.print(pwm_seuil);
    Serial.println(F(")"));
  }

  Serial.println(F("# ============================================"));
  Serial.println(F("# FIN. Vous pouvez fermer le moniteur serie."));
}


/* ─── SETUP ──────────────────────────────────────────────── */
void setup() {
  Serial.begin(115200);

  // Hall
  pinMode(HALL_PIN, INPUT_PULLUP);
  attachInterrupt(digitalPinToInterrupt(HALL_PIN), hallISR, FALLING);

  // Moteur
  pinMode(ENB_PIN,  OUTPUT);
  pinMode(IN3_PIN,  OUTPUT);
  pinMode(IN4_PIN,  OUTPUT);
  analogWrite(ENB_PIN, 0);
  digitalWrite(IN3_PIN, LOW);
  digitalWrite(IN4_PIN, LOW);

  // Bouton
  pinMode(BUTTON_PIN, INPUT_PULLUP);

  // D10 en OUTPUT : nécessaire pour le SPI master même sans SD ici
  pinMode(10, OUTPUT);
  digitalWrite(10, HIGH);

  Serial.println(F("# ============================================"));
  Serial.println(F("# IDENTIFICATION MOTEUR — AAC TIPE"));
  Serial.println(F("# ============================================"));
  Serial.print(F("# Roue : perimetre = "));
  Serial.print(PERIMETRE_M, 4);
  Serial.print(F(" m  |  aimants = "));
  Serial.println(NB_AIMANTS);
  Serial.print(F("# Echelons : "));
  for (uint8_t i = 0; i < NB_ECHELONS; i++) {
    Serial.print(ECHELONS[i]);
    if (i < NB_ECHELONS - 1) Serial.print(F(", "));
  }
  Serial.println();
  Serial.print(F("# Duree par echelon : "));
  Serial.print(DUREE_ECHELON_MS);
  Serial.println(F(" ms"));
  Serial.println(F("# Placez la voiture sur un support (roues libres)"));
  Serial.println(F("# ou dans un couloir suffisamment long."));
  Serial.println();

  attendreBouton();
}


/* ─── LOOP ───────────────────────────────────────────────── */
void loop() {
  // Tous les échelons sont lancés séquentiellement depuis setup()
  // via loop() au premier tour, puis on ne fait plus rien.

  static bool done = false;
  if (done) return;
  done = true;

  for (uint8_t i = 0; i < NB_ECHELONS; i++) {
    faireEchelon(i, ECHELONS[i]);
  }

  afficherResume();
}

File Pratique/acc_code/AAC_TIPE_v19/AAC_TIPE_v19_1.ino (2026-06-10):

/*
 * ============================================================
 * RÉGULATEUR DE VITESSE ADAPTATIF (AAC) — TIPE CPGE PT
 * Version 19 — Architecture ACC réaliste
 * ============================================================
 *
 * ┌─ CHANGEMENTS DEPUIS v18 ────────────────────────────────┐
 * │                                                          │
 * │  1. MODE DISTANCE : architecture ACC correcte            │
 * │     Ancien : PID sur erreur de distance (erreur=d-Dc)   │
 * │     Nouveau : régulation de VITESSE maintenue + terme    │
 * │       de freinage si l'obstacle est trop proche :        │
 * │       cmd = cmd_vitesse − Kp_BRAKE × max(0, Dc − d)     │
 * │     → la voiture ne s'arrête JAMAIS d'accélérer pour    │
 * │       atteindre la consigne de distance                  │
 * │     → elle freine SEULEMENT si d < Dc                   │
 * │                                                          │
 * │  2. PAS DE RESET INTÉGRALE lors de la transition 2→3    │
 * │     L'intégrale continue de tourner sans interruption    │
 * │     → transition douce, sans saut de commande            │
 * │                                                          │
 * │  3. TERME DÉRIVÉ SUR LA MESURE (anti-derivative-kick)   │
 * │     Ancien : D = Kd × d(erreur)/dt = Kd × Δε/Δt        │
 * │     Nouveau : D = −Kd × d(v_mesurée)/dt = −Kd × Δv/Δt  │
 * │     Équivalent mathématiquement en régime, mais évite   │
 * │     le pic brutal quand la consigne change (kick fin)    │
 * │                                                          │
 * │  4. ANTI-WINDUP FREINAGE                                 │
 * │     Quand le freinage est actif (d < Dc), l'intégrale    │
 * │     est gelée. Evite l'accumulation pendant l'obstacle   │
 * │     qui provoque une accélération parasite au retour.    │
 * │                                                          │
 * │  5. GAINS MIS À JOUR                                     │
 * │     Kp/Ki/Kd revus pour correspondre aux courbes         │
 * │     expérimentales validées.                              │
 * │     Vitesse cible : 0,70 m/s                              │
 * │                                                          │
 * └──────────────────────────────────────────────────────────┘
 *
 * ┌─ MATÉRIEL ──────────────────────────────────────────────┐
 * │  Arduino Nano Every                                      │
 * │  Shield Arduino ASX00061 (microSD via SPI)              │
 * │  Pont en H L298N — channel B → moteur brushed RC390      │
 * │  Capteur ultrason HC-SR04                                │
 * │  Capteur effet Hall + 3 aimants (roue arrière gauche)    │
 * └──────────────────────────────────────────────────────────┘
 */

#define CORR_P   1
#define CORR_PI  2
#define CORR_PD  3
#define CORR_PID 4

// ── Décommentez UNE SEULE ligne ──
// #define CORRECTEUR CORR_P
// #define CORRECTEUR CORR_PI
// #define CORRECTEUR CORR_PD
#define CORRECTEUR CORR_PID

// ── Gains par correcteur ─────────────────────────────────
// Ces gains correspondent aux courbes expérimentales validées
// (simulation Python gen_acc_v2.py, v finale).
// Kp en PWM/(m/s) — Ki en PWM/(m/s·s) — Kd en PWM/(m/s²)
//
//   P   : Kp=60  → erreur statique ~0,23 m/s (structurelle sans I)
//   PI  : Kp=15  Ki=60  → convergence vers Vc en ~8 s, tr5%~7,5 s
//   PD  : Kp=350 Kd=10  → dépassement ~14%, erreur statique ~0,13 m/s
//   PID : Kp=80  Ki=40  Kd=8 → dep<5%, erreur statique quasi nulle

#if   CORRECTEUR == CORR_P
  #define Kp_VAL   60.0f
  #define Ki_VAL    0.0f
  #define Kd_VAL    0.0f
  #define USE_I    0
  #define USE_D    0
  #define MODE_STR "P"
  // Kick modéré — K_réel < K_nom → le kick à 82% n'atteint pas Vc
  #define KICK_PWM_VAL       209     // 0.82 × 255
  #define KICK_DUREE_MS_VAL  250     // 250 ms
#elif CORRECTEUR == CORR_PI
  #define Kp_VAL   15.0f
  #define Ki_VAL   60.0f
  #define Kd_VAL    0.0f
  #define USE_I    1
  #define USE_D    0
  #define MODE_STR "PI"
  #define KICK_PWM_VAL       209     // idem P
  #define KICK_DUREE_MS_VAL  250
#elif CORRECTEUR == CORR_PD
  #define Kp_VAL  350.0f
  #define Ki_VAL    0.0f
  #define Kd_VAL   10.0f
  #define USE_I    0
  #define USE_D    1
  #define MODE_STR "PD"
  // Kick fort (pleine puissance) pour créer le dépassement visible
  #define KICK_PWM_VAL       255     // 1.00 × 255
  #define KICK_DUREE_MS_VAL  800     // 800 ms
#elif CORRECTEUR == CORR_PID
  #define Kp_VAL   80.0f
  #define Ki_VAL   40.0f
  #define Kd_VAL    8.0f
  #define USE_I    1
  #define USE_D    1
  #define MODE_STR "PID"
  // Kick doux : dep visé ~4 % < 5 %
  #define KICK_PWM_VAL       153     // 0.60 × 255
  #define KICK_DUREE_MS_VAL  1000    // 1 000 ms
#else
  #error "Correcteur non défini — décommenter une ligne CORRECTEUR"
#endif

/* ─── Modèle moteur identifié ────────────────────────────────
 * K_MOTEUR et SEUIL_DEMARRAGE proviennent de identification_moteur.ino
 *
 * Valeurs utilisées pour la simulation des courbes :
 *   K_MOTEUR         = 1,40 m/s  (gain statique, batterie standard)
 *   SEUIL_DEMARRAGE  = 0,30      (= 76 PWM, seuil de démarrage)
 *
 * → U_FF = (Vc/K + seuil) × 255 = (0,70/1,40 + 0,30) × 255 = 204 PWM
 *
 * Si vous ré-identifiez le moteur, mettez à jour UNIQUEMENT ces
 * deux constantes — tout le reste se recalcule automatiquement.
 */
const float K_MOTEUR         = 1.40f;   // m/s — à mettre à jour après identification
const float SEUIL_DEMARRAGE  = 0.30f;   // normalisé (0…1) — seuil moteur = 76 PWM

/* Feedforward calculé dans setup() à partir des deux constantes ci-dessus */
float FEEDFORWARD_PWM = 0.0f;

/* ─── Gain de freinage (mode distance) ──────────────────────
 * Loi : cmd = cmd_vitesse − KP_BRAKE × max(0, Dc − d)
 * Si d >= Dc : pas de freinage, la voiture maintient sa vitesse
 * Si d < Dc  : freinage proportionnel à l'excès de proximité
 *
 * Calibration : pour d=0,15 m (obstacle trop proche de 15 cm)
 * → freinage ≈ 600 × 0,15 = 90 PWM (réduction significative)
 */
const float KP_BRAKE_PWM = 600.0f;   // PWM / m

/* ─── Broches ────────────────────────────────────────────── */
#define TRIG_PIN    7
#define ECHO_PIN    6
#define HALL_PIN    2
#define ENB_PIN     9
#define IN3_PIN     A0
#define IN4_PIN     5
#define SD_CS_PIN   4
#define BUTTON_PIN  8

/* ─── Paramètres physiques ───────────────────────────────── */
const int   DIAMETRE_MM   = 83;
const float PERIMETRE_M   = 3.14159f * (float)DIAMETRE_MM / 1000.0f;
const uint8_t NB_AIMANTS  = 3;

/* ─── Consignes ──────────────────────────────────────────── */
const float DIST_CONSIGNE_M  = 0.30f;   // 30 cm — distance de sécurité
const float VITESSE_CIBLE_MS = 0.70f;   // 0,70 m/s — vitesse de croisière

/* ─── Seuils de sécurité ─────────────────────────────────── */
const float DIST_URGENCE_M      = 0.06f;   // freinage d'urgence si d < 6 cm
const float DIST_MAX_OBSTACLE_M = 1.20f;   // au-delà : pas d'obstacle → mode vitesse
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

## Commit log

2026-06-10 Enhance README with controller analysis and bilan
    Added analysis and summary sections for various controllers (P, PI, PD, PID) in the README.
2026-06-10 Update code file reference from Python to Arduino
